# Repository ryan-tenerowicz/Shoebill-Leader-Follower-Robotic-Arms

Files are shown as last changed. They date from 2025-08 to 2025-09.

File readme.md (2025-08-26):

# Shoebill Leader & Follower Robotic Arms

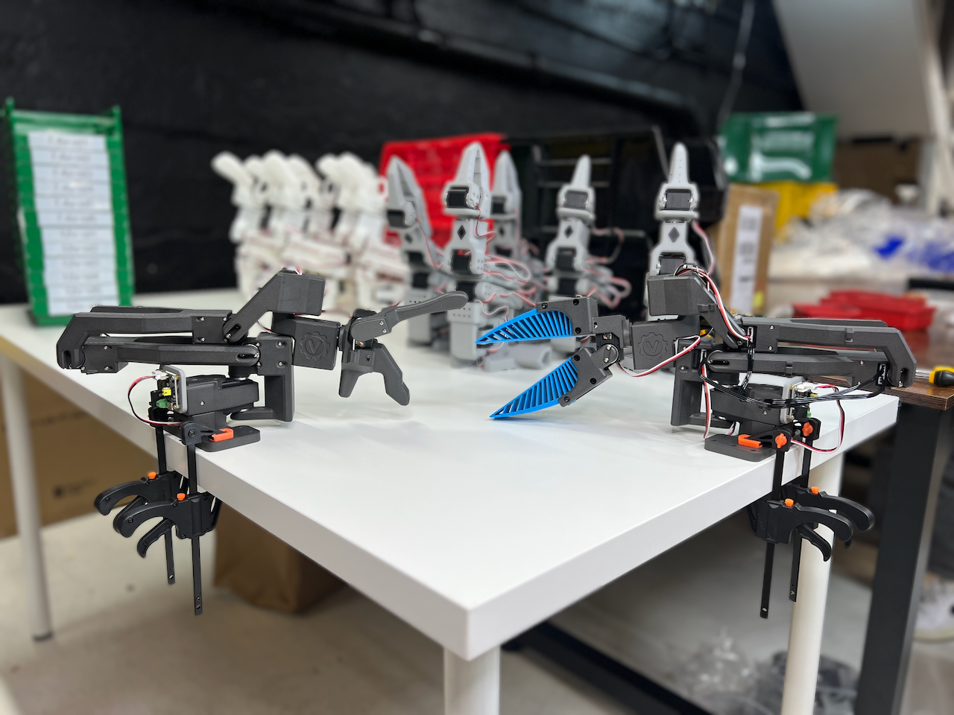
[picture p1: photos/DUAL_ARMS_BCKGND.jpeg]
Shoebill Banner


An open source leader-follower robotic arm system with 7 degrees of freedom, made by Vassar Robotics - inspired by GELLO kinematics, compatible with LeRobot software and common arms in the market (ARX, Trossen, I2RT, etc.)

## Overview

**Shoebill is a leader-follower robotic arm system featuring:**

* **7 DoF articulated movement** with FeeTech servo motors
* **Leader/Follower teleoperation** with 1:1 joint mapping
* **Force feedback capability** via torque position setting
* **LeRobot compatibility** for ACT training policy infrastructure
* **Open source SDK** with pip-installable Vassar-FeeTech servo SDK

Dual Leader - Shoebill Robotics Arm Demo Video (https://www.youtube.com/watch?v=M9KmD0DPkaw)

*Click the image above to watch a Dual Leader set-up (with ARX R5 arms) - Shoebill Robotic Arms Demo*

## Build Guide

### Build Process

1. **[Materials and Components](/mechanicals/mechanicals_readme.md)** - List of materials used
2. **[CAD Files](/mechanicals/)** - OnShape Link, STEP files
3. **[Servo Setup](https://github.com/vassar-robotics/feetech-servo-sdk)** - Configure FeeTech HLS3625 Servos
4. **[Teleoperation Setup](/software/)** - Calibration + Software

### Quick Reference

* **[Bill of Materials](/mechanicals/mechanicals_readme.md)**: Quick overview of materials needed to complete this project
* **[OnShape Link](https://cad.onshape.com/documents/86c64a14309d3dc486db1708/w/d43f2d0114135ce97afe233c/e/5991fe5d18780685a3cfd26c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)**: 3D Print files also available in `/mechanicals/` directory 
* **[Vassar-FeeTech SDK Repository](https://github.com/vassar-robotics/feetech-servo-sdk)**: Use this to configure servos

## Key Features

### Leader Arm
* **GELLO-Inspired Leader Arm Design** - Follows identical kinematics as ARX, Trossen, and I2RT follower arms
* **Custom Torsion-Spring Gripper** - Easy-to-use, normally-open design
* **FeeTech HLS3625 Servos** - Torque position setting capability for force-feedback paradigms

### Follower Arm
* **UMI-Inspired End Effector** - Compliant TPU material for higher dexterity
* **7 Degrees of Freedom** - More closely mimics human joint structure than 6 DoF
* **12V FeeTech Servos** - 3 N·m output torque for more robust performance

## General Resources
* [Vassar Robotics Shop](https://shop.vassarrobotics.com/)
* [LeRobot Documentation](https://huggingface.co/docs/lerobot/en/installation)

## License

_This project is licensed under the MIT License - see the [LICENSE](LICENSE) file for details._

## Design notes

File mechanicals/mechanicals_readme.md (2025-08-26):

### Mechanicals

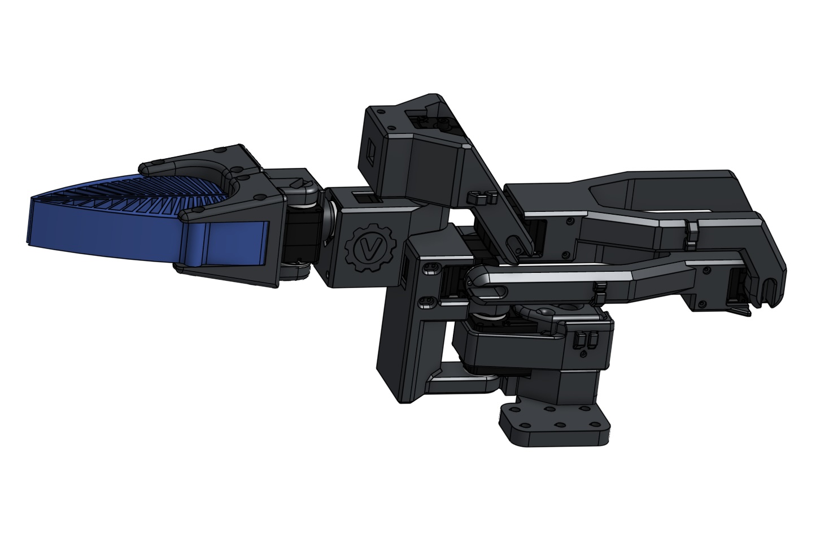
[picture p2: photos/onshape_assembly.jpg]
Onshape assembly


- Onshape CAD model (assembly and all part studios): [Open in Onshape](https://cad.onshape.com/documents/86c64a14309d3dc486db1708/w/d43f2d0114135ce97afe233c/e/20c7a3e319bf2e2af5a60a9c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)
- All mechanical parts are intended to be 3D printed.

### Parts (12 total)

- Shared by both Leader and Follower (7):
  - Base
  - Base-Sleeve
  - L12
  - L23
  - L34
  - L45
  - L56

- Leader-only (2):
  - Handle
  - LeaderGrip

- Follower-only (3):
  - CompliantGripper
  - GripperHolder_Moving
  - GripperHolder_Stationary

### Bill of Materials (additions)

- Torsion spring for Leader Handle — shortened spring from kit: [Amazon torsion spring kit](https://www.amazon.com/dp/B0F9PLNYYF?ref=ppx_yo2ov_dt_b_fed_asin_title). Dimensions: 1.8 mm wire diameter, 14 mm OD coil, 35 mm arm length, 90° angle between arms. The kit includes 4 of the required springs.
- Follower Gripper filament — TPU (Bambu TPU 95A HF): [Product page](https://us.store.bambulab.com/products/tpu-95a-hf?id=41469410607240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).

### Servos & Power

- Leader Arm: 7 FeeTech HLS3625 servos with set-torque capability; 7.4 V power. See the Software section for examples using our open-source FeeTech SDK: [feetech-servo-sdk](https://github.com/vassar-robotics/feetech-servo-sdk).
- Follower Arm: 7 servos — STS3215 or the more robust metal STS3250 — on 12 V power. In our assemblies, we use metal servos (STS3250) on joints 2 and 3 (highest torque), and STS3215 on the remaining joints.
- Control: Both arms use a Waveshare servo driver board. Mixed STS daisy-chaining works correctly with the driver board.

### Assembly reference

- The assembly is analogous to the SO-101. High-quality instructions are available here: [SO-101 assembly guide](https://huggingface.co/docs/lerobot/so101).
- You can also intuit the assembly directly from the Onshape assemblies linked above.
- For the two joints with cantilever beams, add a drop of blue Loctite to the single bolts that go into the servo horns. These are the only two bolts on which the entire assembly depends; Loctite increases long-term reliability.

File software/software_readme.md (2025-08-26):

## Shoebill Arms Software Quick Start

This project’s arms are driven using the Vassar Robotics FeeTech Servo SDK. Use the SDK’s example programs to bring up, calibrate, and teleoperate the leader–follower arms.

### Get the SDK and run the examples
- **Visit the SDK repo**: [Vassar Robotics FeeTech Servo SDK](https://github.com/vassar-robotics/feetech-servo-sdk)
- **Clone and install**:
  ```bash
  git clone https://github.com/vassar-robotics/feetech-servo-sdk.git
  cd feetech-servo-sdk
  pip install -r requirements.txt
  ```
- **Run examples** (from the repo root):
  ```bash
  python examples/teleoperation.py
  python examples/set_middle_position.py
  ```

For environment, connection, and port/ID configuration details, follow the SDK’s README: [SDK README](https://github.com/vassar-robotics/feetech-servo-sdk/blob/main/README.md).

### Teleoperation (leader–follower)
- **File**: [`examples/teleoperation.py`](https://github.com/vassar-robotics/feetech-servo-sdk/blob/main/examples/teleoperation.py)
- **What it does**: Streams joint positions from a manually manipulated leader arm and writes those positions to a follower arm so the follower mirrors the leader in real time.
- **How to use**:
  - Connect both arms to your controller per the SDK README.
  - Ensure servo IDs/ports match your setup (see SDK README for configuration).
  - Run the script; move the leader arm to drive the follower.

### Calibration (set middle position)
- **File**: [`examples/set_middle_position.py`](https://github.com/vassar-robotics/feetech-servo-sdk/blob/main/examples/set_middle_position.py)
- **What it does**: Commands each servo to its middle position (typically value 2048) so both arms share a consistent mechanical zero reference.
- **Why it matters**: Establishes a fixed relative alignment between leader and follower joints, improving tracking accuracy during teleoperation.

### Writing custom control code
The SDK README explains how to write your own control programs, including:
- Initializing controllers and connecting to servos
- Reading/writing positions and feedback
- Setting operating modes (position/speed/torque/PWM)

See: [SDK README](https://github.com/vassar-robotics/feetech-servo-sdk/blob/main/README.md)

### Summary
- Use the SDK’s `/examples` to get the arms working quickly: teleoperation and calibration.
- Refer to the SDK README for configuration and for building custom servo control code.

References: [teleoperation.py](https://github.com/vassar-robotics/feetech-servo-sdk/blob/main/examples/teleoperation.py), [set_middle_position.py](https://github.com/vassar-robotics/feetech-servo-sdk/blob/main/examples/set_middle_position.py), [SDK README](https://github.com/vassar-robotics/feetech-servo-sdk/blob/main/README.md)

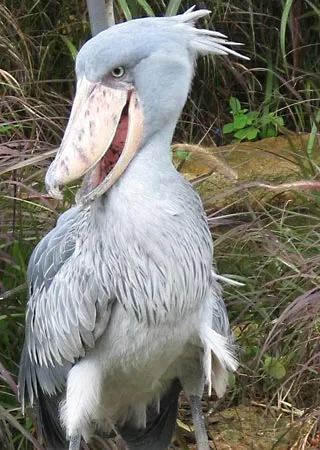
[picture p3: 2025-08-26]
photos/shoebill_stork2.webp

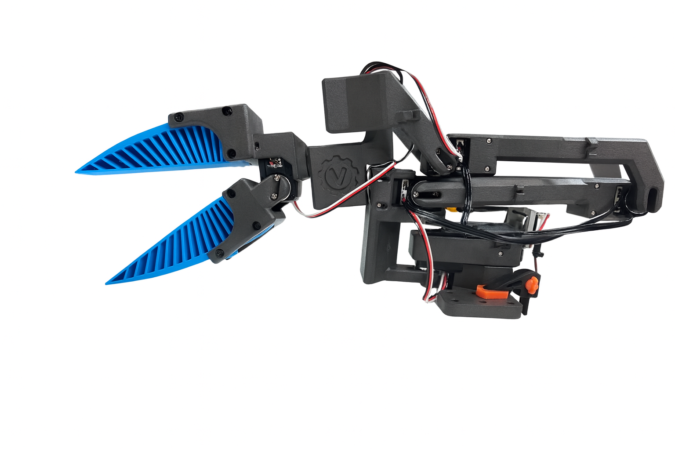
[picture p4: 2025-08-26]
photos/keader_white_bkgnd.png

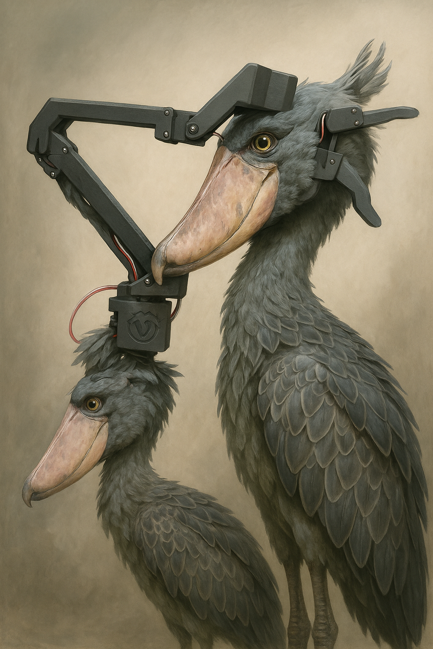
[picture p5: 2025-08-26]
photos/shoebill_meld.png

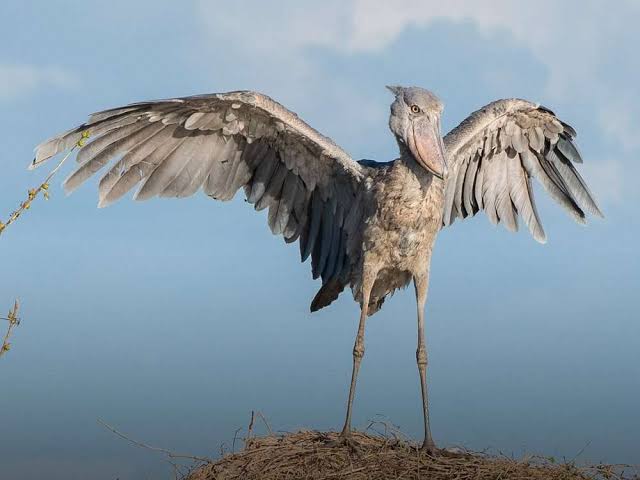
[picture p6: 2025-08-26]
photos/shoebill_stork.jpeg

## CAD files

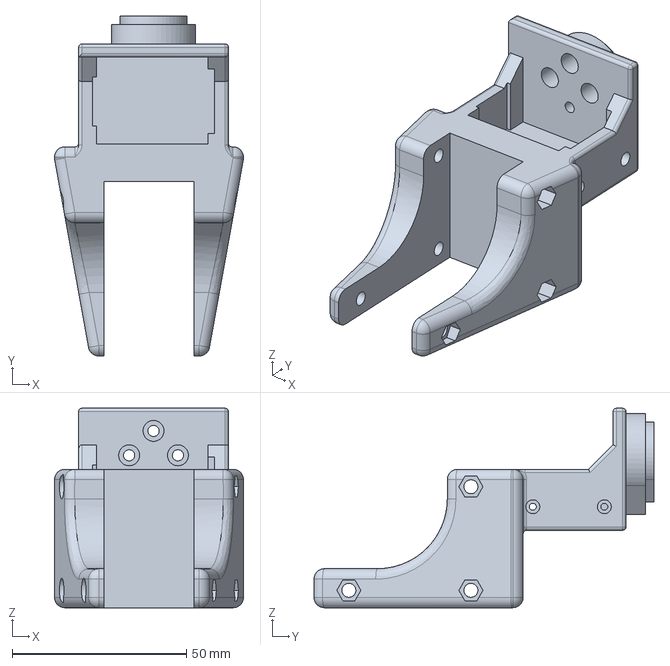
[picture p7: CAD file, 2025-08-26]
mechanicals/Follower End Effector/GripperHolder_Stationary - Part 1.step
54.2 x 97.5 x 57.2 mm

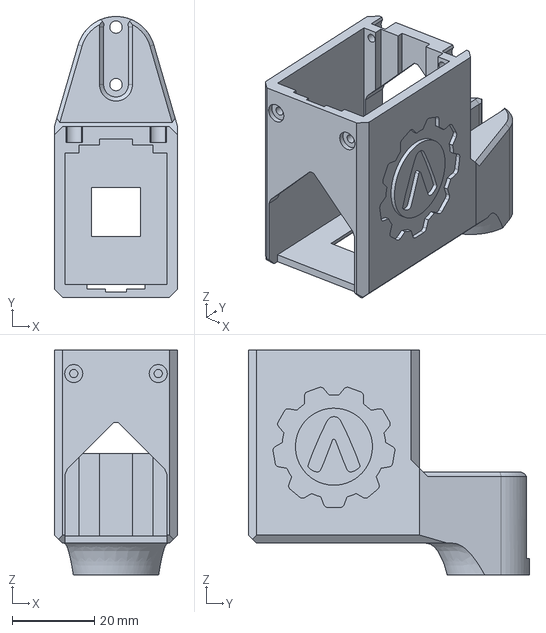
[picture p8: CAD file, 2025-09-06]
mechanicals/L56 - Part 1.step
30.0 x 68.4 x 54.7 mm

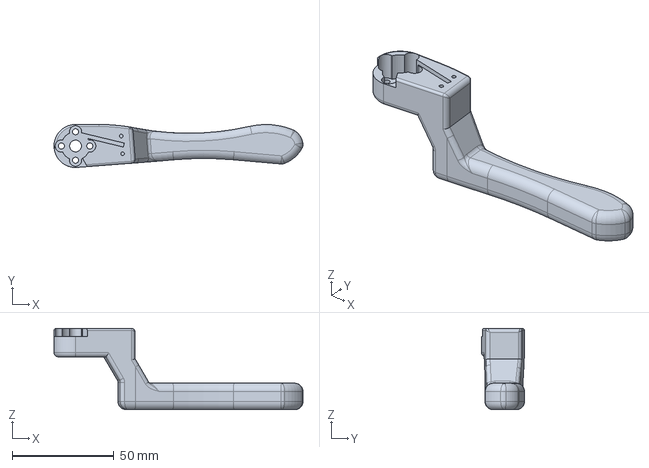
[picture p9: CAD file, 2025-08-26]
mechanicals/Leader End Effector/Handle/Handle - Handle.step
122.5 x 21.2 x 40.0 mm

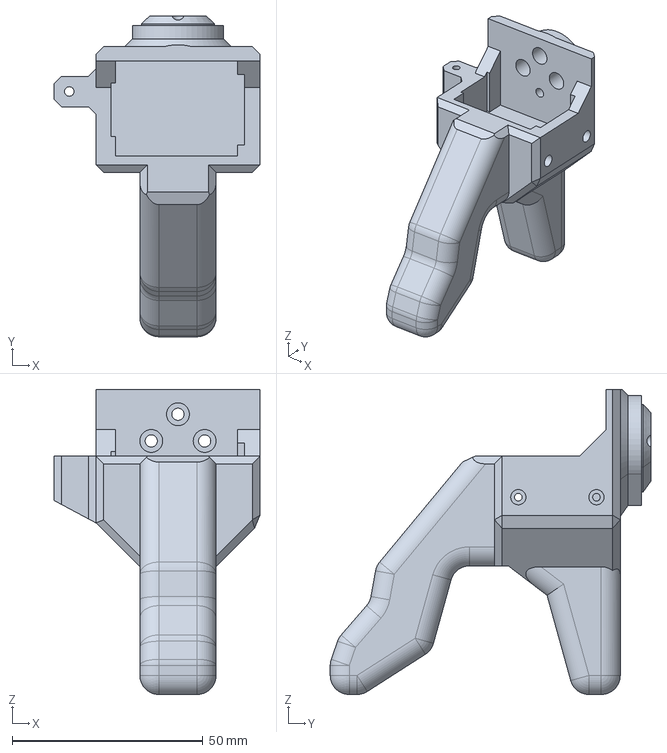
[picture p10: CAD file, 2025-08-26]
mechanicals/Leader End Effector/LeaderGrip - Part 1.step
54.0 x 84.1 x 80.0 mm

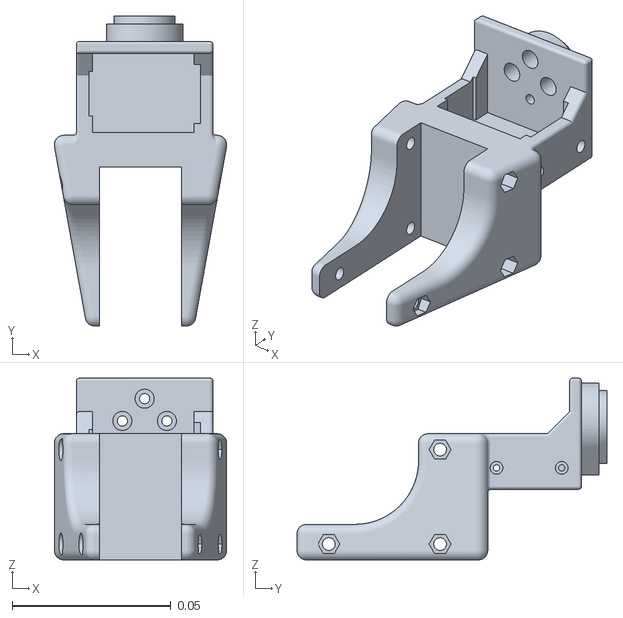
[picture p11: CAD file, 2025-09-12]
mechanicals/urdf/assets/part_1__6.stl
0.0542 x 0.0975 x 0.0572

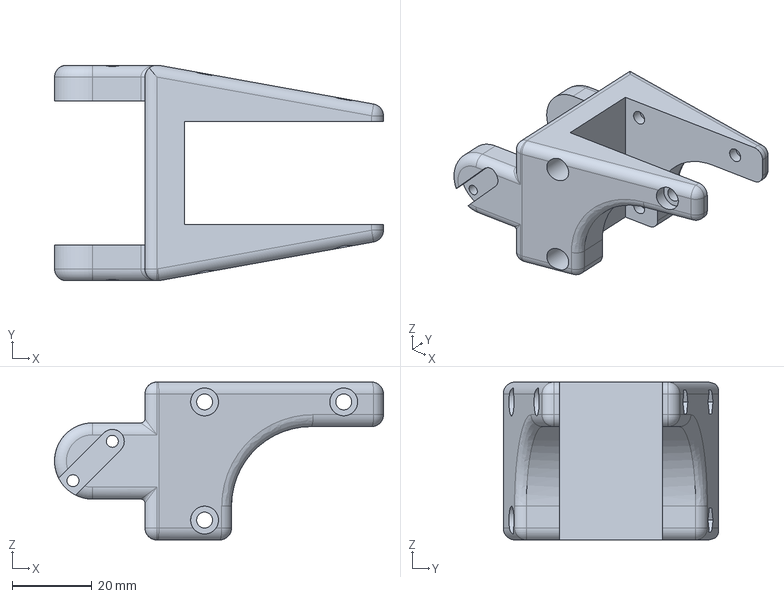
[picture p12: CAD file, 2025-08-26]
mechanicals/Follower End Effector/GripperHolder_Moving - Part 1.step
82.7 x 54.2 x 39.7 mm

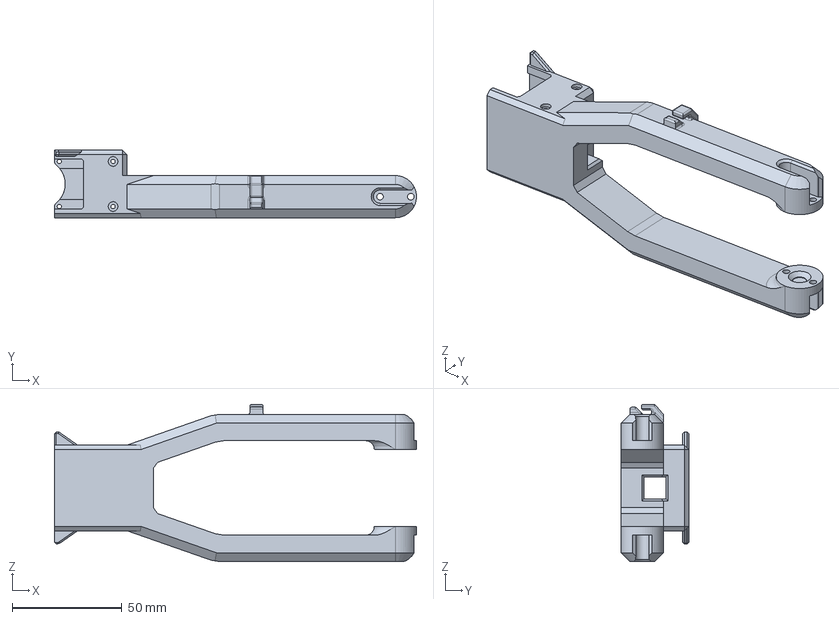
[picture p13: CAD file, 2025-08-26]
mechanicals/L23 - Part 1.step
164.8 x 30.7 x 71.5 mm

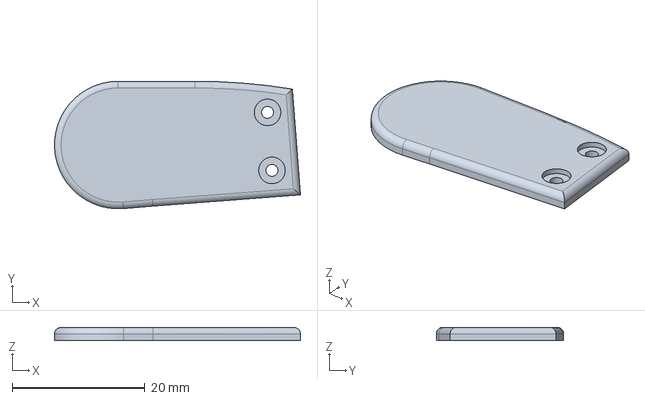
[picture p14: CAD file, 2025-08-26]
mechanicals/Leader End Effector/Handle/Handle - Cap.step
37.0 x 19.2 x 2.00 mm

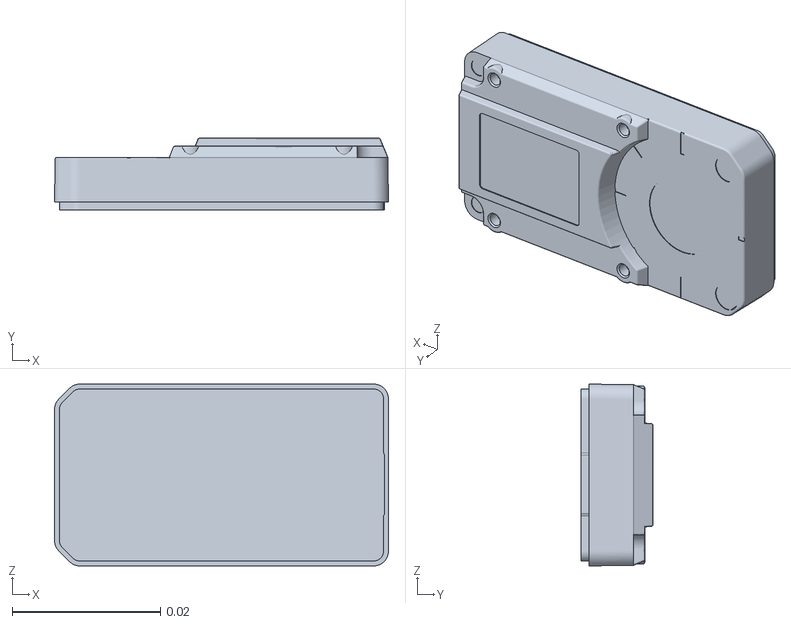
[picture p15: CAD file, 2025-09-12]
mechanicals/urdf/assets/sg_ziji_15.stl
0.045 x 0.0097 x 0.0245

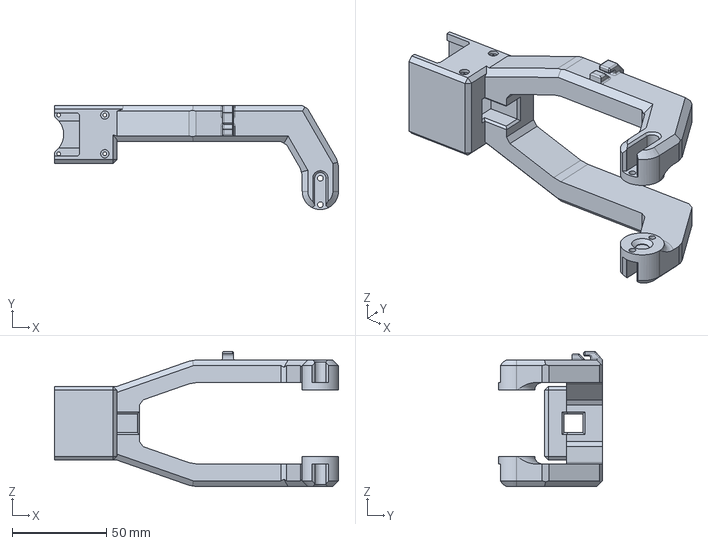
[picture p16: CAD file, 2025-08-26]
mechanicals/L34 - Part 1.step
150.4 x 55.2 x 71.5 mm

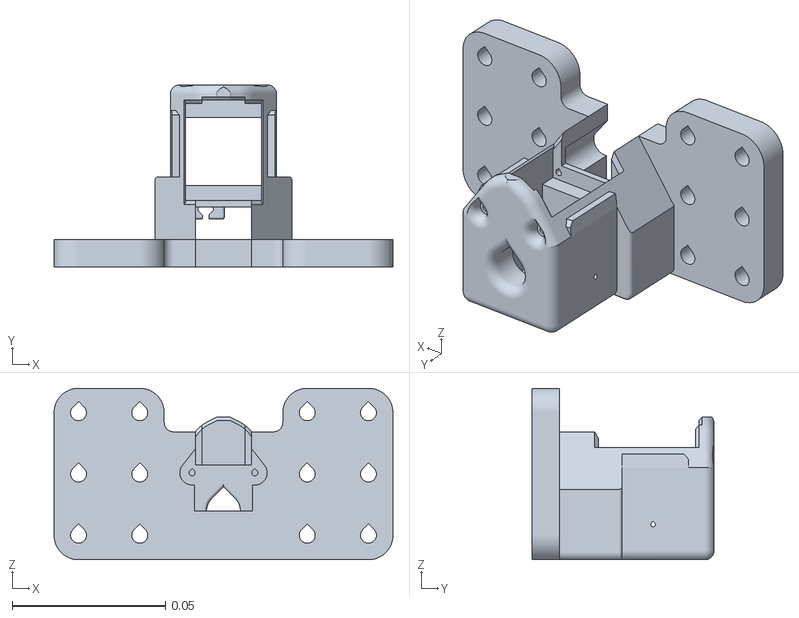
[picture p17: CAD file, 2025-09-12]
mechanicals/urdf/assets/base_so101_v2.stl
0.111 x 0.0595 x 0.056

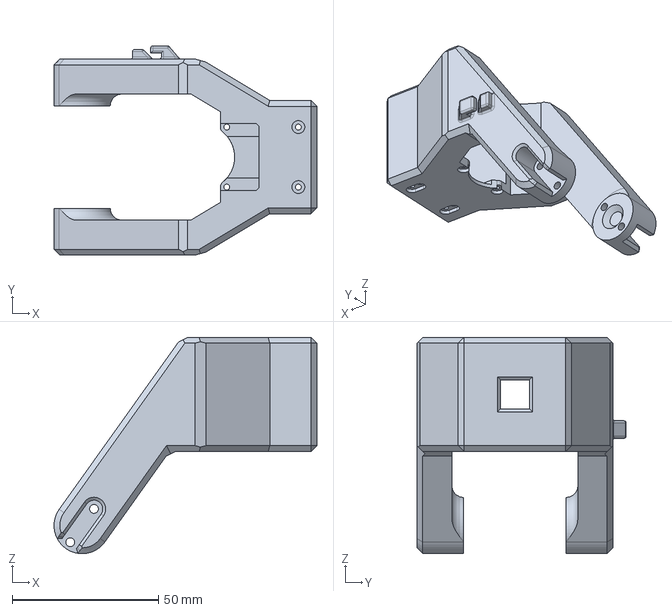
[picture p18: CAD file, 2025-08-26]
mechanicals/L45 - Part 1.step
89.8 x 71.5 x 73.9 mm

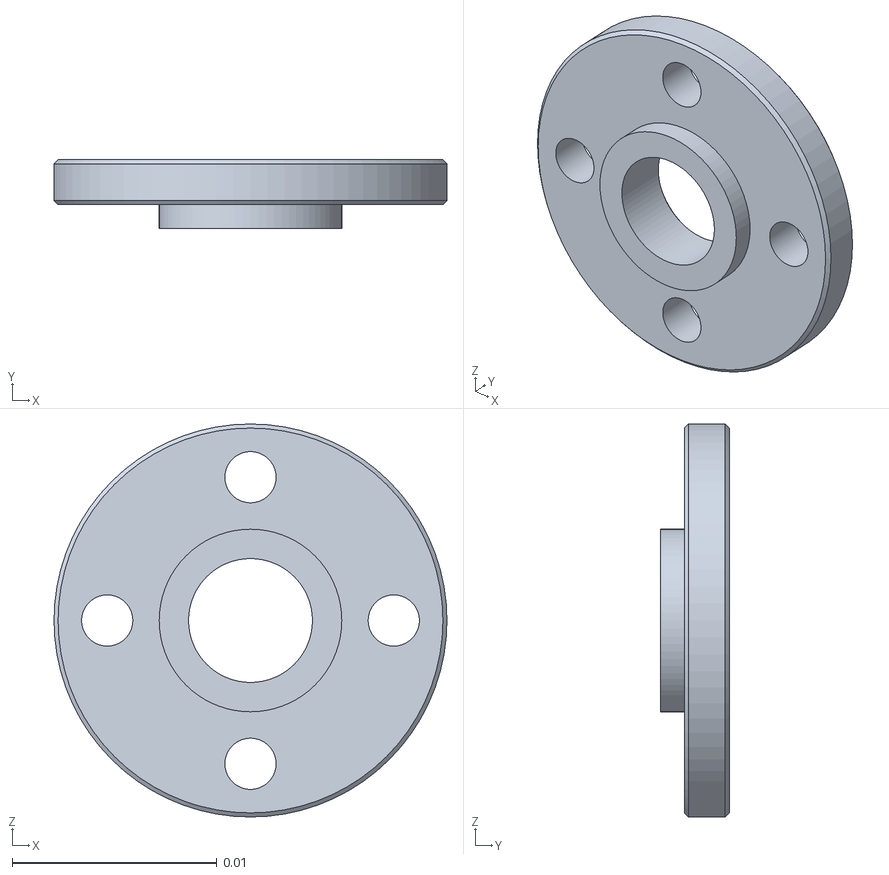
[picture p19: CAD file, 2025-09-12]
mechanicals/urdf/assets/金属舵盘_从动__v2.stl
0.0192 x 0.00335 x 0.0192

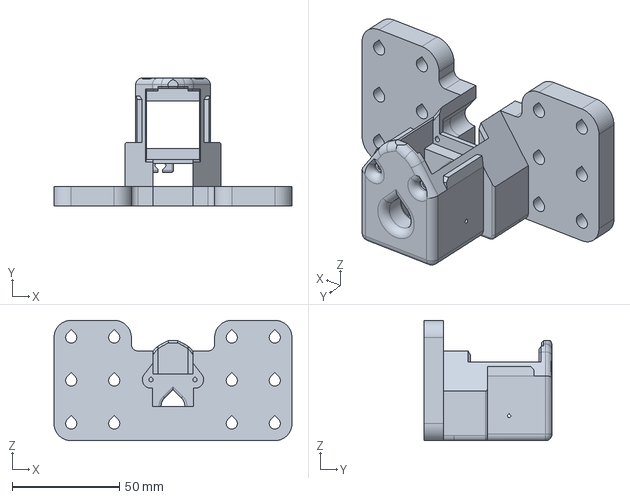
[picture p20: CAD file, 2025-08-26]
mechanicals/Base - Base_SO101 v2.step
110.7 x 59.5 x 56.0 mm

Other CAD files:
mechanicals/urdf/assets/part_1__2.stl
mechanicals/L12 - Part 1.step
mechanicals/urdf/assets/pcb_chazuo_92.stl
mechanicals/Base-Sleeve - Motor1_holder v1.step
mechanicals/urdf/assets/compliantgripper.stl
mechanicals/urdf/assets/ge_27.stl
mechanicals/urdf/assets/motor1_holder_v1.stl
mechanicals/urdf/assets/motor_1723_3.stl
mechanicals/urdf/assets/part_1.stl
mechanicals/urdf/assets/part_1__3.stl
mechanicals/urdf/assets/part_1__4.stl
mechanicals/urdf/assets/part_1__5.stl
mechanicals/urdf/assets/part_1__7.stl
mechanicals/urdf/assets/xg_ziji_16.stl
mechanicals/urdf/assets/zk_122.stl
mechanicals/urdf/assets/金属舵盘_驱动__v2.stl

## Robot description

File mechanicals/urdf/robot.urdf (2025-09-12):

<?xml version="1.0" ?>
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
<robot name="urdf">
  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
  <link name="assembly_2">
    <inertial>
      <origin xyz="0.000371669 -0.0122024 0.041647" rpy="0 0 0"/>
      <mass value="0.0275445"/>
      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
    </inertial>
    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
  </link>
  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
  <link name="assembly_8">
    <inertial>
      <origin xyz="0 0 0" rpy="0 0 0"/>
      <mass value="1e-09"/>
      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
    </inertial>
    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
  </link>
  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
  <link name="assembly_7">
    <inertial>
      <origin xyz="0 0 0" rpy="0 0 0"/>
      <mass value="1e-09"/>
      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
    </inertial>
    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
  </link>
  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
  <link name="assembly_6">
    <inertial>
      <origin xyz="0 0 0" rpy="0 0 0"/>
      <mass value="1e-09"/>
      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
    </inertial>
    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
  </link>
  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
  <link name="assembly_5">
    <inertial>
      <origin xyz="0 0 0" rpy="0 0 0"/>
      <mass value="1e-09"/>
      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
    </inertial>
    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
  </link>
  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
  <link name="assembly_4">
    <inertial>
      <origin xyz="0 0 0" rpy="0 0 0"/>
      <mass value="1e-09"/>
      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
    </inertial>
    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
  </link>
  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
  <link name="assembly_3">
    <inertial>
      <origin xyz="0 0 0" rpy="0 0 0"/>
      <mass value="1e-09"/>
      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
    </inertial>
    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
  </link>
  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
  <link name="assembly_1">
    <inertial>
      <origin xyz="0 0 0" rpy="0 0 0"/>
      <mass value="1e-09"/>
      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
    </inertial>
    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
  </link>
  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
  <joint name="gripper" type="revolute">
    <origin xyz="-0.0207738 -0.0163954 -0.0245" rpy="1.5708 1.56841 1.49096"/>
    <parent link="assembly_3"/>
    <child link="assembly_1"/>
    <axis xyz="0 0 1"/>
    <limit effort="10" velocity="10" lower="-3.141592653589793" upper="3.141592653589793"/>
  </joint>
  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
  <joint name="wrist_rotate" type="revolute">
    <origin xyz="3.81538e-05 0.058816 -0.02" rpy="1.5708 1.5708 0"/>
    <parent link="assembly_4"/>
    <child link="assembly_3"/>
    <axis xyz="0 0 1"/>
    <limit effort="10" velocity="10" lower="-3.141592653589793" upper="3.141592653589793"/>
  </joint>
  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
  <joint name="wrist_pan" type="revolute">
    <origin xyz="0.0411343 0.025675 0.0175" rpy="-1.5708 -1.55484 -6.02423e-15"/>
    <parent link="assembly_5"/>
    <child link="assembly_4"/>
    <axis xyz="0 0 1"/>
    <limit effort="10" velocity="10" lower="-3.141592653589793" upper="3.141592653589793"/>
  </joint>
  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
  <joint name="wrist_raise" type="revolute">
    <origin xyz="0.146391 -0.0325142 0.03615" rpy="-3.14159 -6.43979e-18 0.00578489"/>
    <parent link="assembly_6"/>
    <child link="assembly_5"/>
    <axis xyz="0 0 1"/>
    <limit effort="10" velocity="10" lower="-3.141592653589793" upper="3.141592653589793"/>
  </joint>
  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
  <joint name="elbow_raise" type="revolute">
    <origin xyz="-0.161258 0.005765 -0.00175" rpy="-5.55113e-17 -1.80361e-15 -3.10111e-16"/>
    <parent link="assembly_7"/>
    <child link="assembly_6"/>
    <axis xyz="0 0 1"/>
    <limit effort="10" velocity="10" lower="-3.141592653589793" upper="3.141592653589793"/>
  </joint>
  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
  <joint name="shoulder_raise" type="revolute">
    <origin xyz="-0.0126571 -0.0196019 -0.0252617" rpy="1.5708 6.10606e-16 -3.14144"/>
    <parent link="assembly_8"/>
    <child link="assembly_7"/>
    <axis xyz="0 0 1"/>
    <limit effort="10" velocity="10" lower="-3.141592653589793" upper="3.141592653589793"/>
  </joint>
  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
  <joint name="shoulder_pan" type="revolute">
    <origin xyz="7.98819e-10 -0.04515 0.0569" rpy="-3.14159 -3.63043e-14 1.5708"/>
    <parent link="assembly_2"/>
    <child link="assembly_8"/>
    <axis xyz="0 0 1"/>
    <limit effort="10" velocity="10" lower="-3.141592653589793" upper="3.141592653589793"/>
  </joint>
</robot>

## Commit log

2025-08-26 Add mechanicals README
    [Base - Base_SO101 v2.step, Base-Sleeve - Motor1_holder v1.step, GripperHolder_Moving - Part 1.step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]
2025-08-26 Add servo descripotions
2025-09-06 Add missing 56 part step to mechanicals
    Downloaded from the onshape model
    [L56 - Part 1.step]
2025-09-12 chore: add urdf generated based on onshape model
    Generated from https://onshape-to-robot.readthedocs.io/en/latest/index.html
    [base_so101_v2.stl, compliantgripper.stl, ge_27.stl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]
